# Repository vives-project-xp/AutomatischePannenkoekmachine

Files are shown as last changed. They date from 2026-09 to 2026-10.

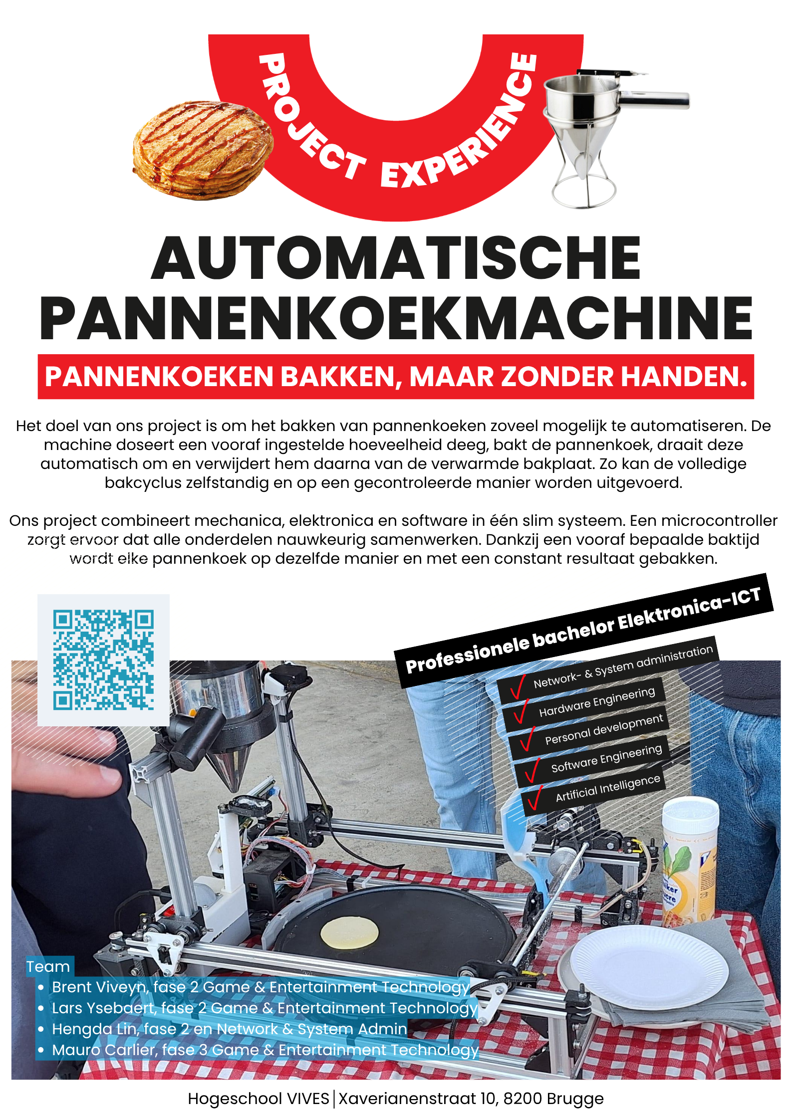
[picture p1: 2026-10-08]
Media/Poster/Poster_versie1.png

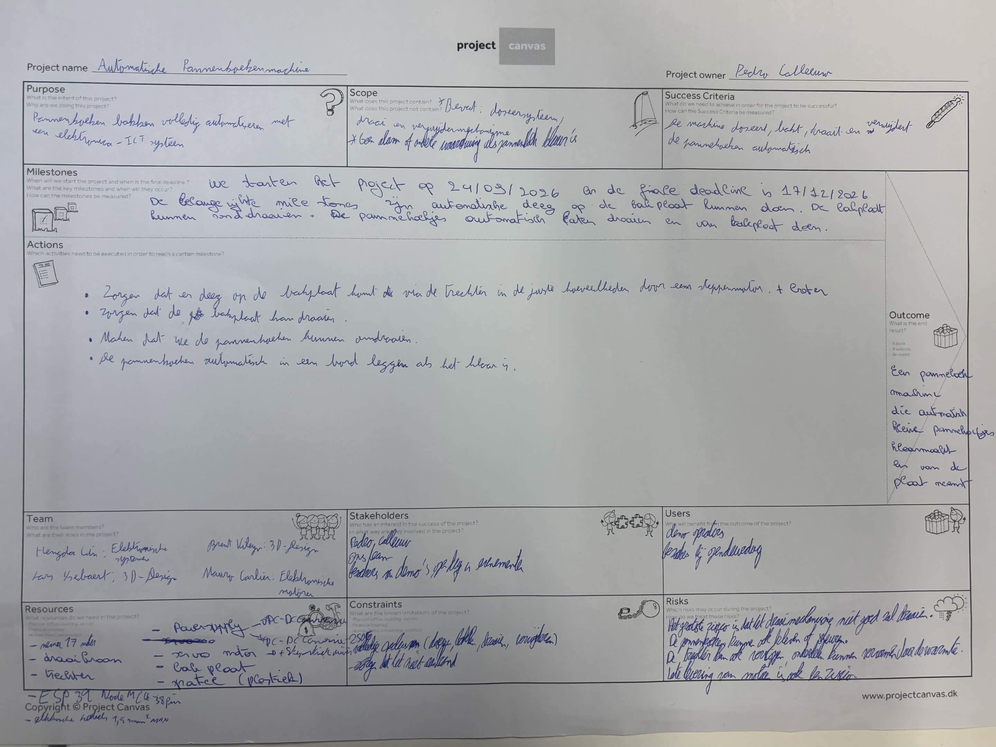
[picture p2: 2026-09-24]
project_canvas.jpg

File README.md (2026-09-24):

# De automatische pannenkoekmachine

Welkom op de projectpagina van onze automatische pannenkoekmachine.

Wij ontwerpen en bouwen een machine die zelfstandig deeg doseert, een pannenkoek bakt, deze omdraait en daarna van de bakplaat verwijdert. Met dit project brengen we mechanica, elektronica en software samen in één geautomatiseerd systeem.

## Ons team

Wij zijn studenten aan VIVES Hogeschool:

| Naam | Opleiding | Studiejaar |
| --- | --- | --- |
| Brent Viveyn | Game & Entertainment Technology | 2de jaar |
| Hengda Lin | Network & System Administration | 2de jaar |
| Lars Ysebaert | Game & Entertainment Technology | 2de jaar |
| Mauro Carlier | Game & Entertainment Technology | 3de jaar |

## Projectpagina's

De onderstaande pagina's worden tijdens het project aangevuld:

- [Projectplanning](docs/projectplanning.md)
- [Mechanisch ontwerp](docs/mechanisch-ontwerp.md)
- [Elektronica en PCB](docs/elektronica-en-pcb.md)
- [Software](docs/software.md)
- [Testen](docs/testen.md)

**Opleiding:** VIVES Hogeschool - Elektronica-ICT

**Product owner:** Pedro Calleeuw

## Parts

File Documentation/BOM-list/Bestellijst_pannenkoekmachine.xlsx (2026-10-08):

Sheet: BOM
Bestellijst automatische pannenkoekmachine (PX3) - hoofdlijst
Prijzen incl. btw volgens de productpagina's op 1 oktober 2026. Blauwe cellen zijn invoer (aantal, prijs); totalen zijn formules. Extra onderdelen staan op het tabblad ‘Extra voorstellen’, 3D-prints op ‘3D-prints’.
# | Categorie | Component | Specificatie | Aantal | Eenheid | Prijs/eenheid (€, incl. btw) | Totaal (€) | Status | Webshop | Artikelnr. | Link | Opmerking
1 | Aandrijving | Stappenmotor NEMA17 40 mm (band ×2 + spatel) | 1,8°/stap · 42,3×42,3×40 mm · 1,2 A · 2,55 V · 4,08 kg·cm · as Ø5×22 mm | 4 | st | €13.50 | €54.00 | Te bestellen | 123-3D | DMO00051 | Open (https://www.123-3d.nl/123-3D-NEMA17-stappenmotor-1-8-graden-per-stap-40-mm-lang-4-08-kg-cm-SL42S240A105-0524-i3421.html)
 |  |  |  |  |  |  |  | Nog te kiezen | – | – | – | Prijs nog onbekend; stuur de gewenste motor door
3 | Aandrijving | Stappenmotordriver DRV8825 (4-pack + koelblokjes) | Vmotor 12–24 V · max 2,5 A · 1/32 microstep · Pololu-footprint | 1 | pak (4) | €22.00 | €22.00 | Te bestellen | 123-3D | DSD00010 | Open (https://www.123-3d.nl/123-3D-Stepstick-DRV8825-driver-aanbieding-4-x-Stepstick-4-x-koelblokjes-i2507.html) | 1 driver per motor
4 | Aandrijving | Stappenmotorkabel 4-draads | 30 cm € 1,70 · 50 cm € 2,25 · 100 cm € 2,80 (hier 50 cm) | 4 | st | €2.25 | €9.00 | Te bestellen | 123-3D | – | https://www.123-3d.nl/123-3D-Stappenmotor-kabel-4-draads-50-cm-i2208.html | Nieuw uit schema; lengte naar opstelling
 |  | GT2 Pulley hoge resolutie | 9 mm riem | 60 tanden | 8 mm as |  | 1 | https://www.123-3d.nl/123-3D-GT2-Pulley-hoge-resolutie-9-mm-riem-60-tanden-8-mm-as-i2573.html
5 | Aandrijving | GT2 pulley 20 tanden (op motor) | 9 mm riem · asgat 5 mm · Ø15 mm · hoogte 20 mm · ook geschikt voor de 6 mm riem | 3 | st | €6.00 | €18.00 | Te bestellen | 123-3D | DME00068 | Open (https://www.123-3d.nl/123-3D-GT2-Pulley-hoge-resolutie-9-mm-riem-20-tanden-5-mm-as-i2305.html) | Aantal bijstellen als de 6 mm riem extra pulleys nodig heeft
6 | Aandrijving | GT2 pulley met lager (zijkant riemen) | Idler · 9 mm riem · asgat 5 mm · aluminium · hoogte 14 mm | 2 | st | €5.50 | €11.00 | Te bestellen | 123-3D | DME00071 | Open (https://www.123-3d.nl/123-3D-GT2-Pulley-hoge-resolutie-met-lager-9-mm-riem-5-mm-as-i2308.html) | Aantal ontbrak in oorspronkelijke lijst; voorstel 1 per band
7 | Aandrijving | GT2 tandriem 9 mm, 5m | Open riem (geen lus) · glasvezel · steek 2 mm | 1 | st | €14.50 | €14.50 | Te bestellen | 123-3D | DME00239 | Open (https://www.123-3d.nl/123-3D-GT2-timing-belt-9-mm-2-5-meter-i6550.html) | Einden moeten geklemd worden (zie tabblad 3D-prints)
8 | Aandrijving | GT2 tandriem 6 mm, gesloten, 200 mm | Gesloten lus · 6 mm breed · steek 2 mm · zelfde tandafstand als de 9 mm riem | 1 | st | €3.50 | €3.50 | Te bestellen | 123-3D | DME00044 | Open (https://www.123-3d.nl/123-3D-GT2-timing-belt-6-mm-gesloten-200-mm-i1704.html) | Zelfde 20T-pulley (DME00068) bruikbaar; aantal pulleys voor deze riem nog te bepalen
9 | Frame | Aluminium profiel 20×20 B-type, sleuf 6 (geanodiseerd) | Sleufbreedte 6 mm · sleufdiepte 5,5 mm · kern voor M6-draad · lengte 1980 mm × 4 st = 7,92 m | 7.92 | m | €4.92 | €38.97 | Te bestellen | https://www.motedis.be/nl/Aluminium-profiel-20x20-B-type-sleuf-6 | 20x20 B-Typ Nut 6 | Open (https://www.motedis.be/nl/Aluminium-profiel-20x20-B-type-sleuf-6) | € 4,07/m excl. = € 4,92/m incl. 21% btw (≈ € 9,74 per stuk van 1980 mm). Lengte 1980 mm = maximale standaardlengte, gratis op maat gezaagd bij bestelling. Aantal 4 stuks is een aanname.
10 | Frame | Kogellager 608 (8×22×7 mm) | Pakket van 6 st; € 3,16 per pakket vanaf 2 pakketten (anders € 3,33) | 14 | pak (6) | €3.16 | €44.24 | Te bestellen | interlager | 1005011757424969 | https://www.interlager.nl/608-2rs-kogellager-8x22x7-mm | 12 lagers = 2 pakketten; levering 6–9 okt
11 | Sensoren | Eindschakelaar micro-switch SPDT | Pakket van 10 st · 12×6×6 mm · 1 A 125 V · kies hendelvariant | 1 | pak (10) | €0.61 | €0.61 | Te bestellen | AliExpress | 4000433828774 | Open (https://nl.aliexpress.com/item/4000433828774.html) | 3 nodig
12
13 | Elektronica | Step-down module LM2596 (24 V → 5 V) | Regelbaar 3–40 V → 1,5–35 V · voedt ESP32 via VIN | 1 | st | €2.20 | €2.20 | Te bestellen | Otronic | – | – | Nieuw uit schema; zoek op productnaam
14 | Voeding | Schakelende voeding LRS-350-24 | 24 V · 14,6 A · 350 W · gesloten behuizing | 1 | st | €37.26 | €37.26 | Te bestellen | Amazon.nl | ASIN B0GG8RGRSR | Open (https://www.amazon.nl/dp/B0GG8RGRSR) | Merk JUNLIN; ingangsschakelaar op 230 V zetten
15 | Dosering & bak | Beslagdispenser RVS | Ø13 × 20 cm · ± 600 ml · drukknop-dosering | 1 | st | €23.39 | €23.39 | Toegekomen | bol | – | Open (https://www.bol.com/be/nl/p/zoezo-design-beslagdispenser-rvs-deeg-dispenser-o13x20-cm-giettrechter-voor-beslag-cupcakes-pannenkoeken-muffins-vaatwasserbestend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) | ZoeZo Design
16 | Dosering & bak | Pannenkoekenmaker 30 cm | COSYLIFE CL-CR3 · 1400 W · thermostaat · Teflon | 1 | st | €19.95 | €19.95 | Toegekomen | Electro Depot | CL-CR3 | Open (https://www.electrodepot.be/nl/pannenkoekmaker-high-one-ho-cr3.html) | Link noemt “High One HO-CR3”; pagina toont COSYLIFE
17 | Aandrijving | Servo DS3218 Pro 20 kg (spatel flip) | 4,8–6,8 V · 18–21,5 kg·cm · waterdicht | 1 | st | €17.95 | €17.95 | Vervalt? | RC Motorsports | – | Open (https://www.rcmotorsports.nl/products/ds-servo-ds3218-pro-waterproof-high-speed-digital-servo-20kg) | Spatel is nu een stappenmotor; niet op voorraad
 |  | Totaal te bestellen (status “Te bestellen”) |  |  |  |  | €255.28

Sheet: Extra voorstellen
Extra voorstellen - nodig of handig voor het schema
Alles hier staat niet in je oorspronkelijke lijst. Prioriteit: Nodig = zonder werkt het schema niet · Aanbevolen · Optioneel · Alternatief = in plaats van iets anders (niet in het totaal).
# | Categorie | Component | Specificatie | Aantal | Eenheid | Prijs/eenheid (€, incl. btw) | Totaal (€) | Prioriteit | Webshop | Artikelnr. | Link | Opmerking
1
2
3
4
5
6 | Elektronica | Condensator elco 330 µF / 35 V radiaal | Eén per DRV8825 over VMOT/GND (minimum 100 µF) | 4 | st | €0.30 | €1.20 | Nodig | Gotron | 330U/35RAD | Open (https://www.gotron.be/componenten/passief/condensatoren/radiale-elco-10v-100v.html) | Link is de categoriepagina (referentie 330U/35RAD)
7 | Elektronica | Weerstandenset 600 st, 30 waarden, 1/4 W 1% | Bevat 10 kΩ en 68 kΩ (R1 = 68 kΩ, R2 = R3 = 10 kΩ) | 1 | set | €3.49 | €3.49 | Nodig | Otronic | – | Open (https://www.otronic.nl/nl/600-weerstanden-set-30-soorten-1-4-watt-1.html) | 75 kΩ zit er niet in; schema gebruikt daarom 68 kΩ
8 | Elektronica | Female header 40 pins 2,54 mm | Voor 8 driver-sockets van 1×8 (bijknippen) | 2 | st | €0.65 | €1.30 | Nodig | Otronic | – | Open (https://www.otronic.nl/nl/40-pins-header-female-254mm.html) | 2 strips = 80 pins, nodig 64
9
10 | Bekabeling | Silicone kabel 18 AWG rood | 255/0,05 · Ø4,5 mm · 24 V-verdeling | 3 | m | €2.75 | €8.25 | Nodig | RC Motorsports | – | Open (https://www.rcmotorsports.nl/products/silicone-kabel-18awg-rood-1-meter-kopie) | Op voorraad
11 | Bekabeling | Silicone kabel 18 AWG zwart | Voor GND, zelfde serie als de rode | 3 | m | €2.75 | €8.25 | Nodig | RC Motorsports | – | Open (https://www.rcmotorsports.nl/products/silicone-kabel-18awg-rood-1-meter-kopie) | Prijs niet bevestigd (zwart niet op de pagina gevonden); verwacht gelijk aan rood
12 | Bekabeling | Adereindhulzen 0,75 mm² blauw (100 st) | Voor de 18 AWG-kabel in schroefklemmen | 1 | pak (100) | €1.36 | €1.36 | Aanbevolen | Gotron | TE7508 | Open (https://www.gotron.be/componenten/connectoren/kabelschoenen/eindhulzen/eindhulzen-0-75mm-blauw-100-stuks.html) | Krimptang apart nodig of met een tang aandrukken
13 | Bekabeling | Soepele montagedraad 1 mm², 5 m zwart | Voor de 230 V-kant (L en N), 1 mm² | 2 | rol (5 m) | €2.89 | €5.78 | Nodig | Gotron | MC1001 | Open (https://www.gotron.be/soepele-montagedraad-5m-zwart-1mm.html) | Enkel zwart gevonden: markeer N met blauwe krimpkous of tape. PE (groen-geel) apart in de winkel kopen.
14 | Bekabeling | Netsnoer Schuko → C13 | 1,5 m, 3×0,75 mm² | 1 | st |  |  | Nodig | – | – | – | Hergebruik een oud pc-/monitor-netsnoer (C13), anders bij Allekabels of bol
15 | Bekabeling | Lasklem WAGO 221-413, 3-voudig (10 st) | 0,2–4 mm² · 32 A · voor splitsen van 24 V en GND | 1 | pak (10) | €13.85 | €13.85 | Optioneel | bol | 221-413 | Open (https://www.bol.com/be/nl/p/wago-lasklem-3-voudig-221-413/9300000009222062/) | Levering uiterlijk 8 okt; alternatief: schroefklemmen
16 | Behuizing | ABS-behuizing IP65 met doorzichtig deksel, 265 × 185 × 95 mm | Voor voeding (215×115×30 mm), buck, drivers en 230 V-deel | 1 | st | €26.41 | €26.41 | Aanbevolen | Gotron | G378C | Open (https://www.gotron.be/waterbestendige-abs-met-doorzichtig-deksel-265x185x95mm.html) | In voorraad in Aalst en Hasselt. Kleinere 200×120 mm-kast is te kort voor de voeding.
17 | Elektronica | ESP32-S breakout met schroefterminals, 38 pins | Voor bekabeling tot de eigen PCB er is | 1 | st | €5.90 | €5.90 | Optioneel | Otronic | – | Open (https://www.otronic.nl/nl/breakout-board-voor-esp32-s-38-pins.html) | 50 op voorraad
18 | Frame | T-sleuf hamermoer B-type sleuf 6, M5 | Metaal · draait 90° bij vastdraaien · past in sleuf 6 van het 20×20 profiel | 20 | st | €0.53 | €10.60 | Nodig | Motedis | S6BHASNM5 | Open (https://www.motedis.be/nl/T-sleuf-hamer-moer-B-type-sleuf-6-M5) | € 0,16 + € 0,28 stuktoeslag excl. = € 0,53 incl. btw per stuk (aanname: toeslag per stuk). Pak van 100 st: € 18,82 incl.
19 | Frame | Metaalschroef inbus M5 × 10 mm verzinkt (50 st) | Bij de hamermoeren M5 (20 nodig) | 1 | pak (50) | €3.55 | €3.55 | Nodig | 123-3D | DBM00061 | Open (https://www.123-3d.nl/123-3D-Metaalschroef-inbus-M5x10-mm-cilinderkop-verzinkt-50-stuks-i1191.html)
20 | Frame | Lageras voor 608-lagers (M8-bout) | Hamerschroef M8 past niet in sleuf 6 (20×20 profiel) | 0 | st |  |  | Alternatief | – | – | – | Vervalt: lagers via 3D-geprinte houder + M8-bout bevestigen; type en aantal nog te bepalen
21 | Mechanica | Metaalschroef inbus M3 × 10 mm verzinkt (50 st) | Motorbevestiging (4 per motor) en klemmen | 1 | pak (50) | €4.55 | €4.55 | Aanbevolen | 123-3D | DBM00042 | Open (https://www.123-3d.nl/123-3D-Metaalschroef-inbus-M3x10-mm-cilinderkop-verzinkt-50-stuks-i1172.html) | M3-moeren erbij kopen indien niet in de print
22 | Frame | Binnenhoek 20 B-type sleuf 6, M5 (pak van 10) | Verzinkt spuitgietzink · 2 stalen schroeven M5×6 meegeleverd · interne montage | 1 | pak (10) | €6.26 | €6.26 | Nodig | Motedis | S6BIBM5 | Open (https://www.motedis.be/nl/Interne-hoek-20-B-type-sleuf-6-M5-Alternative) | € 5,17 excl. = € 6,26 incl. btw per 10 st (€ 0,52/st). Vervangt de 3D-geprinte hoeken; 8 nodig, 2 reserve.
 |  | Totaal Nodig (met prijs) |  |  |  |  | €48.68
 |  | Totaal Aanbevolen (met prijs) |  |  |  |  | €32.32
 |  | Totaal Optioneel (met prijs) |  |  |  |  | €19.75
 |  | Alternatief (niet meegeteld) |  |  |  |  | €0.00
 |  | Enige regel zonder prijs: netsnoer Schuko → C13 (hergebruik een oud pc-netsnoer). Die zit niet in de totalen.

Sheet: 3D-prints
3D-prints
Blauwe cellen zijn invoer. Gewicht, tijd en filamentkost rekenen automatisch mee met het aantal. Aantallen zijn aannames tot je frame vaststaat.
# | Onderdeel | Model (link) | Profiel / maat | Materiaal | Instellingen | Gewicht per stuk (g) | Printtijd per stuk (min) | Aantal | Totaal gewicht (g) | Totale tijd (uur) | Status | Opmerking
1 | Hoekverbinder “bracket 4040” | Open (https://makerworld.com/en/models/1677812-bracket-4040-bracket-for-4040-profiles) | 40×40 · I-type groef 8 | PETG | laag 0,28 mm · 3 wanden · 15% vulling | 15 | 49 | 0 | 0 | 0.0 | Vervalt | Voor 40×40 profiel; vervalt door de overstap naar 20×20 (metalen binnenhoeken van Motedis in tabblad Extra voorstellen).
2 | Hoekverbinder “Angle Slot 10 with Guide” | Open (https://makerworld.com/nl/models/2376384-40x40-angle-slot-10-with-guide) | 40×40 · groef 10 (type B) | PETG | laag 0,2 mm · 3 wanden · 25% vulling | 13 | 37 | 0 | 0 | 0.0 | Vervalt | Voor 40×40 profiel met groef 10; vervalt door de overstap naar 20×20.
3 | Riemklem GT2 (open riem) | Open (https://www.printables.com/model/816496-gt2-belt-clamps) | 6 mm en 10 mm riem | PETG of PLA | ontwerper: PLA, 205 °C |  |  | 4 |  |  | Gebruiken | Voor de open 9 mm riem: kies de 10 mm variant. Aantal 4 = 2 banden × 2 uiteinden (aanname). Gewicht en tijd niet vermeld.
 | Totaal te printen (status Gebruiken) |  |  |  |  |  |  |  | 0 | 0.0
 | Materiaal
 | Filament | Open (https://www.123-3d.nl/123-3D-Filament-PETG-Mat-Zwart-1-75-mm-1-kg-DFS10112c-i12176.html) | PETG filament mat zwart 1,75 mm, 1 kg
 | Webshop / artikelnr. |  | 123-3D · DHM00249
 | Prijs per spoel (€, incl. btw) |  | €26.50
 | Aandeel in deze prints (€) |  | €0.00
 | Spoelen nodig (afgerond naar boven) |  | 0
 | Heb je al PETG of PLA liggen? Dan kan de spoel vervallen. Riemklem-gewicht ontbreekt in het model, dus wordt niet meegeteld.

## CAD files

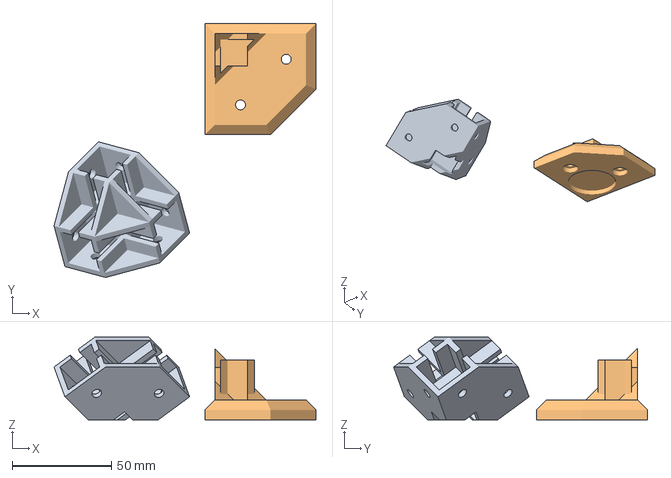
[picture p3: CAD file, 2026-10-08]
Hardware/3D-Files/3_Way_Corner_Bracket_with_Foot_(2020).3mf
132.0 x 127.9 x 41.6 mm
Corner Bracket (2020).STEP
Corner Bracket Foot (2020).STEP

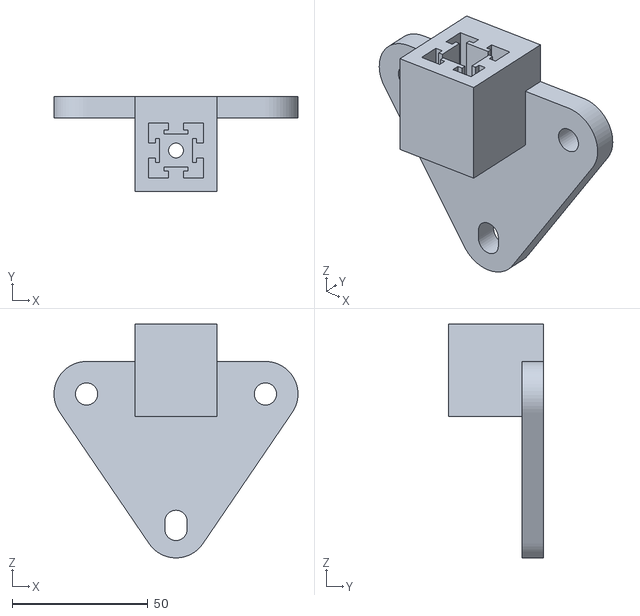
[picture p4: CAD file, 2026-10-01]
Hardware/3D-Files/bearing holder profiel.stl
90.0 x 35.2 x 86.2

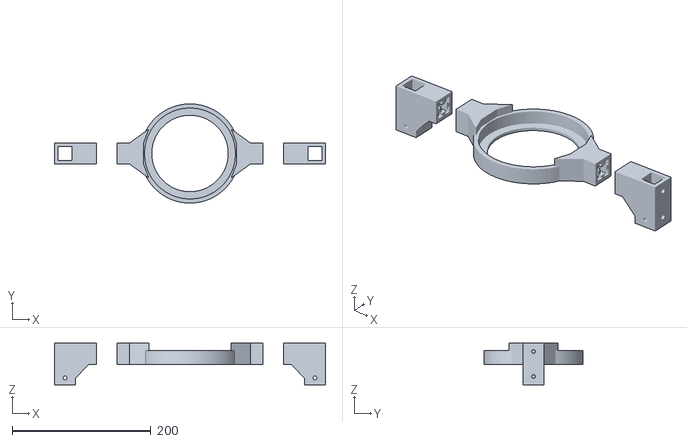
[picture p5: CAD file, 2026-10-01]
Hardware/3D-Files/Trechter_holder.stl
390.4 x 142.9 x 60.0

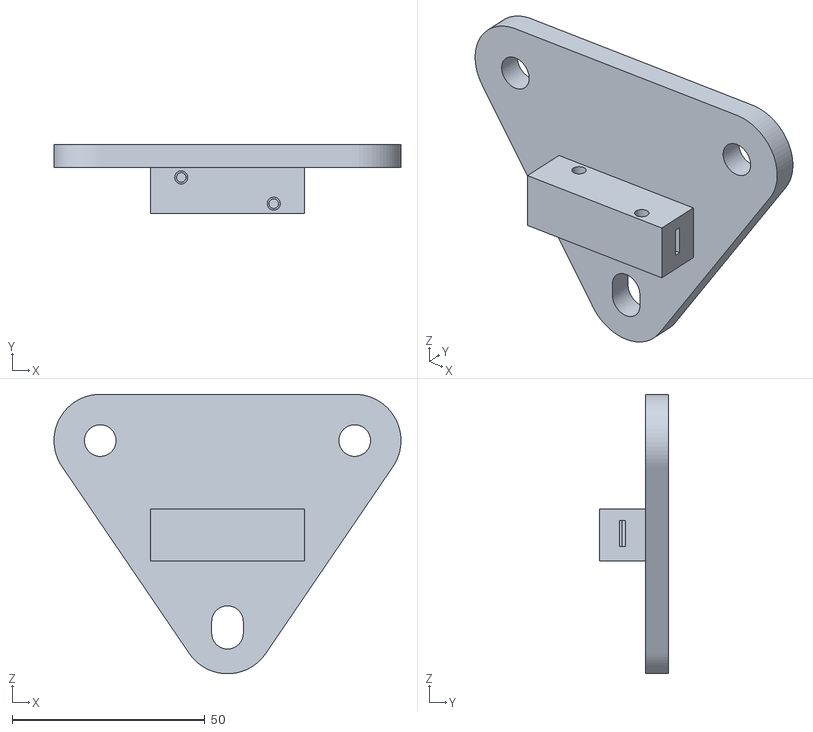
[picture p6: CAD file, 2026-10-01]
Hardware/3D-Files/band holder.stl
90.0 x 18.0 x 72.4

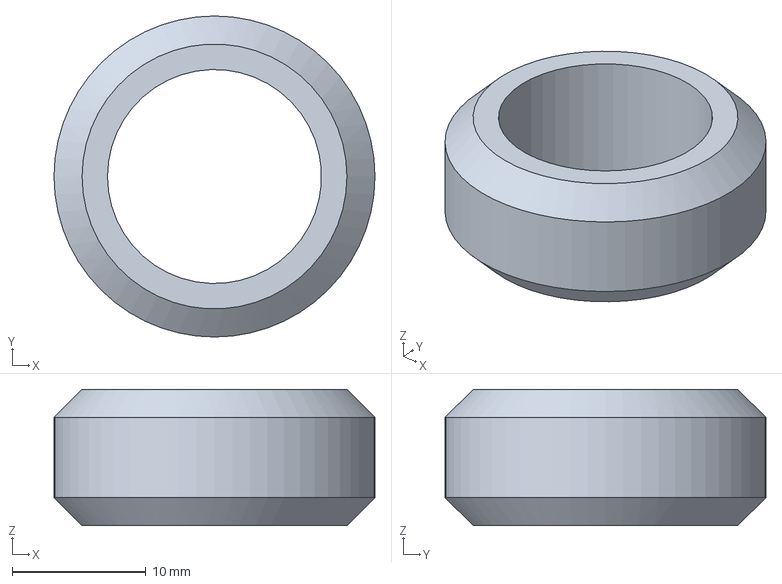
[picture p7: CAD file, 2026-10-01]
Hardware/3D-Files/V+Slot+Wheel.3mf
24.0 x 24.0 x 10.2 mm

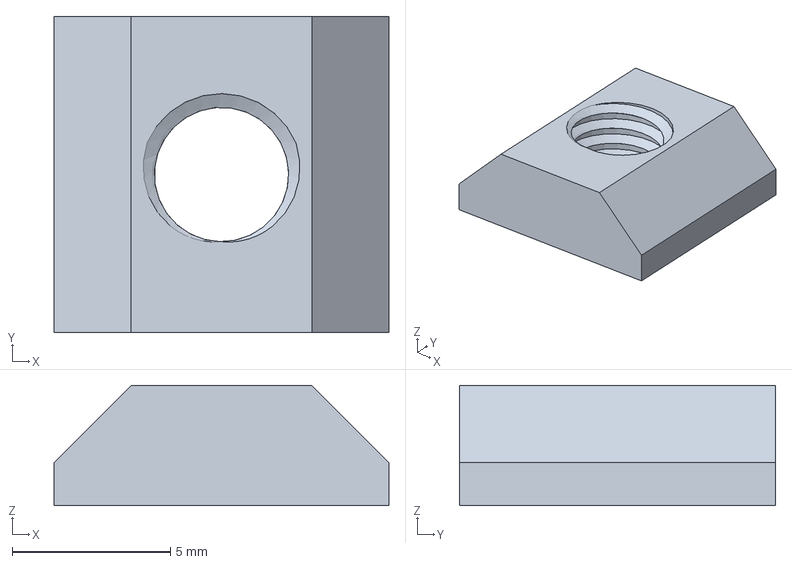
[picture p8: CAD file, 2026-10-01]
Hardware/3D-Files/T+Nut+v2.3mf
10.6 x 10.0 x 3.80 mm

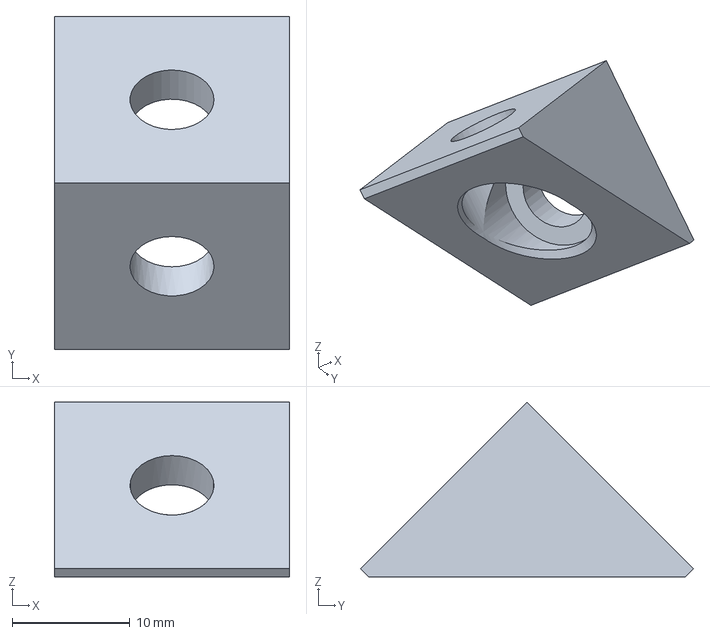
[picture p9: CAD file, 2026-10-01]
Hardware/3D-Files/Corner_Bracket.3mf
20.0 x 28.3 x 14.8 mm

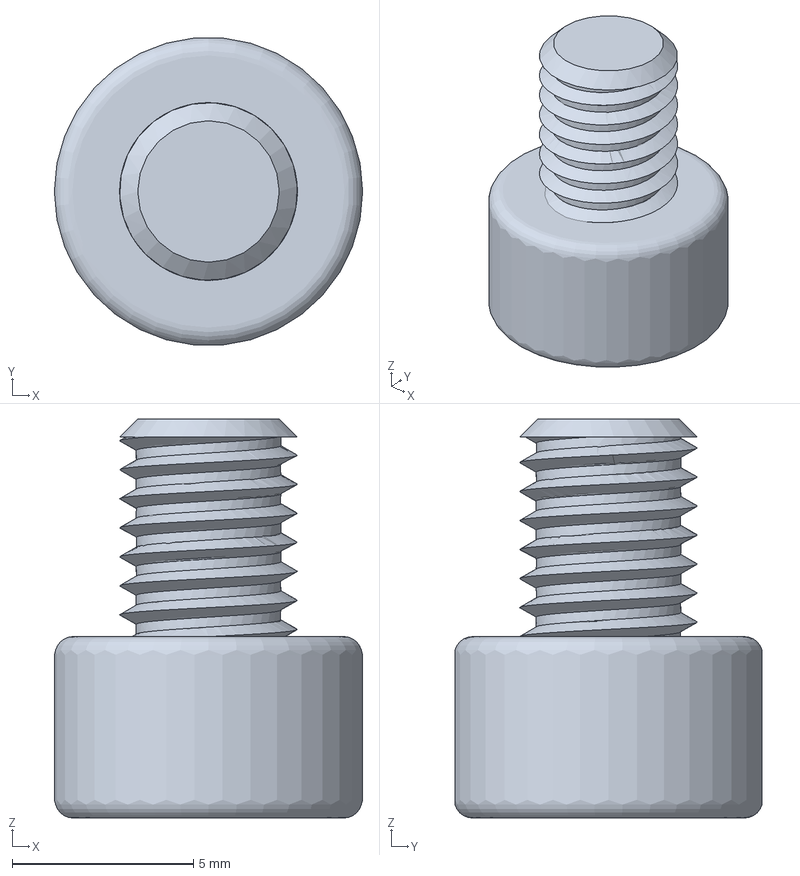
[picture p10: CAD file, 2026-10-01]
Hardware/3D-Files/M5_x_6mm_Cap_Screw.3mf
8.50 x 8.47 x 11.0 mm

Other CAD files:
Hardware/visuele voorstelling px3.f3d

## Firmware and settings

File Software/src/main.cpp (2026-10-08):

/*
 * main.cpp
 *
 * Opstarten en hoofdlus van de automatische pannenkoekmachine, plus de
 * seriele testinterface (115200 baud). In deze stap wordt alleen de bandas
 * aangestuurd. De loop blokkeert nooit: veiligheid en as worden bij elke
 * doorgang bijgewerkt en seriele tekens worden een voor een ingelezen.
 */
#include <Arduino.h>
#include <FastAccelStepper.h>

#include "band_axis.h"
#include "config.h"
#include "safety.h"

FastAccelStepperEngine engine;  // gedeeld door alle (toekomstige) assen
BandAxis band;

// ---------------------------------------------------------------------------
// Seriele commando's
// ---------------------------------------------------------------------------
static void toonHelp() {
  Serial.println(F("Commando's:"));
  Serial.println(F("  home            homing op S1"));
  Serial.println(F("  goto <mm>       absolute positie"));
  Serial.println(F("  move <mm>       relatief, mag negatief"));
  Serial.println(F("  speed <mm/s>    maximale snelheid"));
  Serial.println(F("  accel <mm/s2>   versnelling"));
  Serial.println(F("  stop            rustig afremmen"));
  Serial.println(F("  enable/disable  drivers aan/uit"));
  Serial.println(F("  status          toestand tonen"));
  Serial.println(F("  reset           fout wissen"));
}

static void toonStatus() {
  Serial.printf("Toestand : %s\n", band.toestandNaam());
  Serial.printf("Positie  : %.2f mm\n", band.positieMm());
  Serial.printf("Gehomed  : %s\n", band.isGehomed() ? "ja" : "nee");
  Serial.printf("S1       : %s\n", Safety::s1Geraakt() ? "GERAAKT / kabel los" : "vrij");
  Serial.printf("Noodstop : %s\n",
                !Safety::spanningAanwezig() ? "ACTIEF (geen 24 V)"
                : Safety::vergrendeld()     ? "24 V ok, wacht op 'reset'"
                                            : "ok (24 V aanwezig)");
  Serial.printf("Enabled  : %s\n", Safety::driversAan() ? "ja" : "nee");
  Serial.printf("Snelheid : %.1f mm/s, versnelling %.1f mm/s2\n",
                band.snelheid(), band.versnelling());
  if (band.toestand() == BandAxis::Toestand::ERROR) {
    Serial.printf("Fout     : %s\n", band.foutTekst());
  }
}

// Leest het getal achter een commando. Komma en punt zijn allebei toegestaan.
static bool leesGetal(char *tekst, float &waarde) {
  if (tekst == nullptr) return false;
  for (char *p = tekst; *p; p++) {
    if (*p == ',') *p = '.';
  }
  char *einde;
  waarde = strtof(tekst, &einde);
  return einde != tekst && *einde == '\0' && isfinite(waarde);
}

static void voerUit(char *regel) {
  char *cmd = strtok(regel, " \t");
  char *arg = strtok(nullptr, " \t");
  if (cmd == nullptr) return;  // lege regel
  for (char *p = cmd; *p; p++) *p = tolower(*p);

  float getal = 0;
  bool isGetalCommando = !strcmp(cmd, "goto") || !strcmp(cmd, "move") ||
                         !strcmp(cmd, "speed") || !strcmp(cmd, "accel");
  if (isGetalCommando && !leesGetal(arg, getal)) {
    Serial.printf("Gebruik: %s <getal>\n", cmd);
    return;
  }

  if (!strcmp(cmd, "home")) {
    band.home();
  } else if (!strcmp(cmd, "goto")) {
    if (band.gaNaar(getal)) Serial.printf("Naar %.2f mm\n", getal);
  } else if (!strcmp(cmd, "move")) {
    if (band.verplaats(getal)) Serial.printf("Verplaats %+.2f mm\n", getal);
  } else if (!strcmp(cmd, "speed")) {
    if (band.zetSnelheid(getal)) Serial.printf("Snelheid = %.1f mm/s\n", getal);
  } else if (!strcmp(cmd, "accel")) {
    if (band.zetVersnelling(getal)) Serial.printf("Versnelling = %.1f mm/s2\n", getal);
  } else if (!strcmp(cmd, "stop")) {
    band.stop();
    Serial.println(F("Stop: afremmen"));
  } else if (!strcmp(cmd, "enable")) {
    if (Safety::zetDrivers(true)) {
      Serial.println(F("Drivers AAN"));
    } else {
      Serial.println(F("Geweigerd: noodstop actief, herstel 24 V en typ 'reset'."));
    }
  } else if (!strcmp(cmd, "disable")) {
    band.vrijgeven();  // eerst de pulsen stoppen, dan pas de drivers uit
    Safety::zetDrivers(false);
    Serial.println(F("Drivers UIT (band moet opnieuw gehomed worden)"));
  } else if (!strcmp(cmd, "status")) {
    toonStatus();
  } else if (!strcmp(cmd, "reset")) {
    // Eerst de noodstop-vergrendeling: lukt alleen als de 24 V terug is
    if (!Safety::reset()) {
      Serial.println(F("Reset geweigerd: nog geen 24 V (noodstop ingedrukt?)."));
    } else if (band.resetFout()) {
      Serial.println(F("Fout gewist. Typ 'enable' en daarna 'home'."));
    } else {
      Serial.println(F("Reset mislukt."));
    }
  } else if (!strcmp(cmd, "help") || !strcmp(cmd, "?")) {
    toonHelp();
  } else {
    Serial.printf("Onbekend commando '%s', typ 'help'.\n", cmd);
  }
}

// Verzamelt tekens tot een volledige regel, zonder te wachten.
static void leesSerieel() {
  static char buffer[48];
  static size_t lengte = 0;

  while (Serial.available() > 0) {
    char c = (char)Serial.read();
    if (c == '\r' || c == '\n') {
      buffer[lengte] = '\0';
      lengte = 0;
      voerUit(buffer);
    } else if (lengte < sizeof(buffer) - 1) {
      buffer[lengte++] = c;
    }
  }
}

// ---------------------------------------------------------------------------
// Setup en loop
// ---------------------------------------------------------------------------
void setup() {
  Serial.begin(SERIEEL_BAUD);
  Serial.println();
  Serial.println(F("=== Automatische pannenkoekmachine - bandas ==="));

  Safety::begin();  // als eerste: drivers uit en noodstop controleren

  engine.init();
  if (!band.begin(engine)) {
    Serial.println(F("!! FOUT: stappenmotor BAND kon niet worden aangemaakt."));
  }

  toonHelp();
}

void loop() {
  Safety::update();  // noodstop en eindschakelaars
  band.update();     // toestandsmachine van de band
  leesSerieel();     // testinterface
}

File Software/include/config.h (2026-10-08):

/*
 * config.h
 *
 * Alle pinnen en instelbare constanten van de pannenkoekmachine op een plek.
 * Wil je iets aan de hardware of de afstelling wijzigen (pin, snelheid,
 * slaglengte, draairichting), dan doe je dat hier en nergens anders.
 */
#pragma once

#include <Arduino.h>

// ---------------------------------------------------------------------------
// Pinnen
// ---------------------------------------------------------------------------
constexpr uint8_t PIN_STEP_BAND  = 25;  // STEP, gedeeld door beide banddrivers
constexpr uint8_t PIN_DIR_BAND   = 26;  // DIR, gedeeld door beide banddrivers
constexpr uint8_t PIN_EN_DRIVERS = 13;  // EN van ALLE drivers, actief LAAG
constexpr uint8_t PIN_S1_HOME    = 16;  // eindschakelaar S1 (NC naar GND)
constexpr uint8_t PIN_NOODSTOP   = 35;  // 24V-detectie (input-only)

// Gereserveerd voor latere uitbreidingen (nog niet gebruikt):
//   27 / 14  STEP / DIR spatelmotor
//   32 / 33  STEP / DIR draaimotor
//   17 / 18  extra eindschakelaars
//   21 / 22  I2C (SDA / SCL)
//   23       SSR bakplaat
//   34       NTC temperatuurmeting
// Niet gebruiken: 0, 2, 5, 12, 15 (strapping) en 6-11 (flash).

// ---------------------------------------------------------------------------
// Mechanica van de band
// ---------------------------------------------------------------------------
// 200 stappen/omw * 16 microstappen = 3200 stappen/omw
// GT2-riem, 20 tanden * 2 mm = 40 mm/omw  ->  3200 / 40 = 80 stappen/mm
constexpr float STEPS_PER_MM = 80.0f;

constexpr float SLAGLENGTE_MM = 600.0f;  // bruikbare slag (nog na te meten)

// Draairichting: true = DIR hoog laat de positie oplopen (weg van S1).
// Rijdt de brug bij 'home' WEG van S1, zet dit dan op false.
constexpr bool DIR_HOOG_TELT_OP = true;

// ---------------------------------------------------------------------------
// Bewegingsprofiel
// ---------------------------------------------------------------------------
constexpr float MAX_SNELHEID_MM_S  = 50.0f;   // startwaarde na opstarten
constexpr float VERSNELLING_MM_S2  = 200.0f;  // startwaarde na opstarten

// Bovengrenzen voor de commando's 'speed' en 'accel' (tegen typfouten)
constexpr float SNELHEID_LIMIET_MM_S   = 200.0f;
constexpr float VERSNELLING_LIMIET_MM_S2 = 2000.0f;

// ---------------------------------------------------------------------------
// Homing
// ---------------------------------------------------------------------------
constexpr float HOME_SNELHEID_SNEL_MM_S  = 10.0f;  // eerste benadering
constexpr float HOME_SNELHEID_TRAAG_MM_S = 2.0f;   // tweede, nauwkeurige benadering
constexpr float HOME_TERUGRIJ_MM         = 5.0f;   // terugrijden na eerste contact
constexpr float HOME_EXTRA_ZOEK_MM       = 50.0f;  // marge bovenop de slaglengte

// Afstand tussen het schakelpunt van S1 en positie 0. Zo is S1 op positie 0
// weer vrij en geeft 'goto 0' geen valse eindschakelaarfout.
constexpr float HOME_OFFSET_MM = 3.0f;

// ---------------------------------------------------------------------------
// Veiligheid en communicatie
// ---------------------------------------------------------------------------
constexpr uint32_t ONTDENDER_MS = 5;       // ontdendertijd eindschakelaars
constexpr uint32_t SERIEEL_BAUD = 115200;

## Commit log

2026-10-01 Trechter houder added
    [Trechter_holder.stl, bearing holder profiel.stl]
2026-10-01 kleine connectore en rollementen
    [Corner_Bracket.3mf, M5_x_6mm_Cap_Screw.3mf, T+Nut+v2.3mf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]
2026-10-01 Van 40x40 naar 20x20 gemaakt
    [Trechter_holder.stl, band holder.stl, bearing holder profiel.stl]
2026-10-08 mappenstructuur gefixtµ
    [Corner_Bracket.3mf, M5_x_6mm_Cap_Screw.3mf, T+Nut+v2.3mf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]
2026-10-08 3d file hoek
    [3_Way_Corner_Bracket_with_Foot_(2020).3mf]
2026-10-08 eerste versie BOM lijst en mappenstructuur
    [Bestellijst_pannenkoekmachine.xlsx]
2026-10-08 fusion overzicht van totaalplaatje
    [3_Way_Corner_Bracket_with_Foot_(2020).3mf, visuele voorstelling px3.f3d]
2026-10-22 2e versie van de band holder
2026-10-22 Stappen motor aansturen documentatie
2026-10-22 steppen motor holder voor de 2 lange banden gemaakt
2026-10-29 bearing holder V3 en pully holder gemaakt
2026-10-29 trechter opener frame toegevoegd
2026-10-29 stepperholder stang gemaakt, dit is voor de stepper motor die de stang zal laten draaien
2026-10-29 bearing holder voor de stang gemaakt
